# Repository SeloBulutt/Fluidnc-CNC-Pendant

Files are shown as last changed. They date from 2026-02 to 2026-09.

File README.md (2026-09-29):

# 🎛️ CNC Pendant for FluidNC

**Arduino Nano ESP32 tabanlı (farklı mikroişlemci kullanabilirsiniz), ST7789 TFT ekranlı, FluidNC uyumlu CNC kumanda paneli.**

> Tasarım & Geliştirme: **VOLTveTORK**  
> Sürüm: **v7.0** — Modüler Mimari, SD Kart G-Code Çalıştırma & Canlı İlerleme Takibi, NVS Durdurma Noktası Kayıt Sistemi, Z Probe Desteği, PWM Ekran Parlaklığı, Asenkron WiFi Tarama, Gelişmiş Güvenlik & Performans İyileştirmeleri

---

## 📸 Özellikler

### Temel Özellikler
- ✅ FluidNC ile **UART + WiFi/TCP** çift kanallı haberleşme
- ✅ Gerçek zamanlı **Machine Position (MPos)** ve **Work Position (WPos)** gösterimi
- ✅ Rotary encoder ile hassas jog kontrolü (interrupt tabanlı, 60ms throttle)
- ✅ 4 buton: HOME / ZERO / EKSEN / HIZ-STEP
- ✅ Encoder kısa tıklama + uzun basma (500ms) desteği
- ✅ X, Y, Z eksen seçimi
- ✅ Durum göstergesi: IDLE / RUN / HOLD / ALARM / HOME / JOG / DOOR
- ✅ Homed durumu takibi
- ✅ **Z Probe Desteği** (G38.2 ile derinlik ve hız ayarlı otomatik prob)
- ✅ **PWM Ekran Parlaklık Kontrolü** (4 kademeli arka ışık seviyesi)
- ✅ **Ayar Kalıcılığı (Preferences / NVS)** (Step, Hız, Eksen ve Parlaklık hafızada saklanır)
- ✅ **Tam Modüler C++ Mimarisi** (Bakımı ve geliştirmesi kolay 5 bağımsız modül)
- ✅ **Non-blocking Altyapı** (delay() içermeyen pop-up ve arka planda asenkron WiFi işlemleri)
- ✅ **Gelişmiş Güvenlik:** RUN, HOLD ve ALARM durumlarında kazara hareketi önleyen jog kilidi
- ✅ Popup bildirimleri (non-blocking)
- ✅ **Alt menülerde sınırsız bekleme süresi** (Otomatik çıkış kaldırıldı)
- ✅ **SD Kart Dosya Gezgini** (`$SD/List` & `$SD/Run` ile doğrudan pendant üzerinden G-code dosya listeleme ve çalıştırma)
- ✅ **G-Code Ön İzleme Ekranı** (SD karttaki dosyanın G-code satırlarını kaydırmalı olarak görüntüleme ve AXIS butonuyla başlatma)
- ✅ **Canlı İş İlerleme Ekranı (SCR_JOB_PROGRESS)** (İlerleme çubuğu, yüzde, senkron aktif G-code satırı, Feed ve Spindle bilgileri ile anlık takip)
- ✅ **Durdurma Noktası Kayıt Sistemi (NVS Flash)** (Duraklatma veya Alarm anında kalınan satır no, G-code komutu, WPos koordinatları ve dosya adı kalıcı belleğe kaydedilir)
- ✅ **SPEED Butonu ile Duraklat / Devam Et** (Kesim anında Feed Hold `!` ile duraklatma ve Cycle Start `~` ile devam)
- ✅ **Kesim Anı Tuş Güvenliği** (Kesim sırasında yanlışlıkla basılmaları önlemek için ZERO tuşu ve Jog kilitlenir)

### 🆕 v7.0 — Modüler Mimari, Non-blocking Yapı, Z Probe ve Performans İyileştirmeleri

#### 🔧 Çözülen Sorunlar & Yapılan İyileştirmeler

| Sorun / İhtiyaç | Açıklama | Çözüm |
|---|---|---|
| **Pop-up Delay Bloklaması** | Pop-up bildirimleri gösterilirken `delay()` kullanıldığı için sistem geçici olarak kilitleniyor, veri akışı duruyordu. | **Non-blocking Pop-up** mimarisine geçildi (`PopupState`). Bildirimler arka planda sayılır, sistem akışı kesilmez. |
| **WiFi Bağlantı Bloklaması** | `while(WiFi.status())` döngüsü WiFi bağlanırken tüm sistemi bloke ediyor ve ekranı donduruyordu. | **State Machine (Durum Makinesi)** altyapısına geçildi (`wcsState`). Bağlantı arka planda kurulur. |
| **WiFi Tarama Donması** | Ağ taraması yapılırken (`scanNetworks`) tüm ekran ve arayüz donuyordu. | **Asenkron WiFi taraması** (`WiFi.scanNetworks(true)` + polling) eklendi; tarama arka planda yapılır. |
| **Heap Parçalanması (Çökme Riski)** | Dinamik `String +=` birleştirmeleri ESP32 RAM belleğinde parçalanmaya (fragmentation) yol açıyordu. | Sabit boyutlu **char buffer (`char fcBuf[128]`)** yapısına geçildi, bellek sızıntısı ve çökme riski ortadan kaldırıldı. |
| **Ekran Titremesi (Flicker)** | Her ekran yenilemede `fillScreen()` çağrılması gözü yoran titremelere neden oluyordu. | **Partial Update (Kısmi Güncelleme)** ile sadece değişen alanlar çizilerek titreme minimuma indirildi. |
| **Pil Dalgalanması** | Her döngüde analog voltaj okunması pil yüzdesinde sürekli oynamalara neden oluyordu. | **Önbellekleme & Filtre:** Pil 10 saniyede bir, 8 örnek ortalaması alınarak gürültüden arındırıldı. |
| **RUN/HOLD Modunda İstem Dışı Jog** | Makine çalışırken encoder'a yanlışlıkla dokunulması iş parçasına çarpma riski doğuruyordu. | `ST_RUN`, `ST_HOLD` ve `ST_ALARM` durumlarında encoder jog komutları **yazılımsal olarak engellendi**. |
| **Yeniden Başlatmada Ayar Kaybı** | Cihaz kapatıldığında step, hız, eksen ve ekran ayarları varsayılana dönüyordu. | **Preferences (NVS)** API'si ile ayarlar kalıcı hafızaya kaydedildi; açılışta otomatik geri yüklenir. |
| **Monolitik Kod Karmaşası** | 2400+ satırlık tek `.ino` dosyası kodun bakımını, takibini ve geliştirilmesini zorlaştırıyordu. | Kod **5 modüle ayrıldı** (`config`, `input`, `fluidnc`, `wifi_mgr`, `display`). |
| **SD Kart Dosya Başlatma** | SD karttaki G-code dosyaları pendant üzerinden görüntülenemiyor ve başlatılamıyordu. | FluidNC `$SD/List` ve `$SD/Run` entegrasyonu sağlandı; menüye **SD Kart Dosya Gezgini** ve **Ön İzleme** eklendi. |
| **G-Code İlerleme & Satır Takibi** | Kesim sırasında makinenin hangi satırda olduğu ve dosya ilerlemesi kumanda ekranında izlenemiyordu. | **Canlı İş İlerleme Ekranı** (`SCR_JOB_PROGRESS`) geliştirildi; `Ln:` veya `sdPercent` ile senkron aktif G-code satır gösterimi sağlandı. |
| **Durdurma Anında Bilgi Kaybı** | Acil durdurma, duraklatma veya alarmlarda işin nerede kaldığı bilinemiyordu. | **NVS Kalıcı Durdurma Noktası Kaydı** eklendi; dosya adı, satır numarası, o satırdaki G-code komutu ve koordinatlar Flash hafızaya kaydedilir. |
| **E-Stop / Alarm Anında Çökme** | Acil stop butonuna basıldığında pendant çöküyor ve bootloop döngüsüne giriyordu. | Format hatası (`%%.1f`) ve `prefs.begin()` güvenlik kontrolleri düzeltildi, çökme riski tamamen ortadan kaldırıldı. |
| **Kesim Anında Yanlışlıkla Sıfırlama** | Kesim sırasında ZERO tuşuna basılması parça sıfırını bozabilirdi. | `ST_RUN` ve `ST_HOLD` durumlarında ZERO butonu yazılımsal olarak devre dışı bırakıldı. |

#### ✨ Yeni Eklenen Özellikler

- ✅ **Z Probe Ekranı (#18)** — Menüye yeni "Z Probe" özelliği eklendi! `G38.2` komutu ile hassas sıfırlama yapılır. Menü üzerinden prob derinliği (`-1` ile `-50 mm`) ve prob hızı (`20` ile `500 mm/dk`) encoder ile ayarlanabilir. IDLE modunda Eksen butonuna basılarak tetiklenir.
- ✅ **PWM Ekran Parlaklık Ayarı (#19)** — A2 (TFT_BLK) pini üzerinden 4 kademeli PWM parlaklık kontrolü (%25, %50, %75, %100). WiFi menüsünden doğrudan değiştirilebilir.
- ✅ **Kalıcı Ayar Hafızası (NVS / Preferences) (#20)** — Step boyutu, Jog hızı, seçili eksen ve ekran parlaklık seviyesi cihaz kapatılsa bile hafızada saklanır.
- ✅ **RUN/HOLD Jog Kilidi (#1)** — İşleme veya alarm durumlarında istenmeyen fiziksel jog hareketlerini engelleyen güvenlik koruması.
- ✅ **Float Epsilon Karşılaştırma (#8)** — Pozisyon değişimlerinde hassas floating point karşılaştırması (`fabsf(a-b) > 0.0005`).
- ✅ **Merkezi MachineState Enum (#13)** — String karşılaştırmaları yerine enum mimarisi ile maksimum hız ve güvenilirlik.
- ✅ **SD Kart Dosya Gezgini (`$SD/List` & `$SD/Run`)** — UART veya WiFi üzerinden SD karttaki `.nc`, `.gcode` dosyaları listelenir, encoder ile seçilir.
- ✅ **G-Code Ön İzleme Ekranı (`SCR_SD_PREVIEW`)** — SD karttaki dosyaya tıklandığında hemen başlatılmaz; G-code satırları kaydırmalı olarak incelenir, EKSEN (AXIS) butonu ile başlatılır.
- ✅ **Canlı İş İlerleme ve Takip Ekranı (`SCR_JOB_PROGRESS`)** — İş başlatıldığında otomatik açılır:
  - Duruma göre renkli başlık (İŞ ÇALIŞIYOR / DURAKLATILDI / ALARM DURUMU!)
  - Dinamik ilerleme çubuğu (yüzde ve anlık satır / toplam satır sayısı)
  - Feed hızı, Spindle devri ve dosya adı göstergesi
  - Makine hareketiyle senkron olarak kayan canlı G-code satırları
  - HOME butonu ile ana menüye dönülebilir, menüden tekrar ilerleme ekranına girilebilir
- ✅ **Durdurma Noktası Kayıt Sistemi (NVS Flash)** — Kesim anında SPEED ile duraklatıldığında veya beklenmedik bir E-Stop/Alarm oluştuğunda dosya adı, kalınan satır, o satırdaki G-code komutu, WPos koordinatları kalıcı hafızaya yazılır. Cihaz kapansa bile silinmez.
- ✅ **E-Stop / Alarm Güvenliği ve Çökme Koruması** — Bellek taşması ve `printf` formatlama hataları giderilerek E-Stop anındaki reset/çökme sorunu tamamen çözüldü.
- ✅ **Kesim Anında ZERO Tuşu Güvenlik Kilidi** — Kesim esnasında (`ST_RUN`, `ST_HOLD`) ZERO butonuna basılsa bile koordinat sıfırlama engellendi.

### v6.0 — mDNS Otomatik IP Keşfi, TCP Donma Çözümü, UART Öncelikli İletişim

#### 🔧 Çözülen Sorunlar

| Sorun | Açıklama | Çözüm |
|---|---|---|
| **TCP Bağlantı Donması** | `tcpClient.connect()` FluidNC'ye ulaşamadığında ~5 saniye boyunca sistemi tamamen donduruyordu. Bu her 5 saniyede bir tekrarlanarak "5sn dondur, 5sn çalış" döngüsü oluşturuyordu. | `connect()` çağrısına **1000ms timeout** parametresi eklendi. Sistem artık en fazla 1 saniye bloke olur. |
| **Manuel IP Girişi Zorluğu** | FluidNC'nin IP adresini kullanıcının encoder ile tek tek girmesi gerekiyordu. IP adresi değiştiğinde tekrar elle güncelleme yapılmalıydı. | **mDNS (ESPmDNS)** ile FluidNC'nin ağda yayınladığı `fluidnc.local` adresi otomatik keşfedilir. WiFi bağlantısı kurulduğunda IP otomatik bulunur. |
| **UART Aktifken Gereksiz TCP Denemeleri** | UART bağlantısı aktifken bile TCP reconnect denemeleri yapılıyor, bu her denemede sistemi kısa süreli donduruyordu. | UART aktifken TCP reconnect denemeleri **tamamen engellendi**. Sadece UART pasif olduğunda TCP bağlantısı denenir. |
| **Header'da Belirsiz Bağlantı Göstergesi** | Bağlantı durumu ikonunda UART mı yoksa WiFi mı kullanıldığı net anlaşılmıyordu. | Header'da **`[UART]`** (yeşil) ve **`[WiFi]`** (yeşil/sarı) olarak ayrı ayrı gösterilir. Aktif kanal net şekilde belirtilir. |
| **TCP Reconnect Sıklığı** | Başarısız TCP bağlantı denemelerinde her 5 saniyede bir yeniden deneme yapılıyordu, bu da sürekli donma hissi yaratıyordu. | **Üstel geri çekilme (exponential backoff)** eklendi: İlk 3 deneme → 5sn, sonraki 7 → 15sn, ardından → 30sn aralıklarla deneme yapılır. |

#### ✨ v6.0 ile Eklenen Özellikler

- ✅ **mDNS ile Otomatik IP Keşfi** — WiFi bağlantısı kurulduğunda FluidNC'nin ağdaki IP adresi **otomatik olarak keşfedilir** (`ESPmDNS` kütüphanesi). Manuel IP girişine gerek kalmaz. TCP bağlantısı 3 kez başarısız olursa mDNS ile IP tekrar aranır.
- ✅ **UART Öncelikli İletişim** — UART bağlantısı aktifse (500ms içinde veri geliyorsa) tüm komutlar UART üzerinden gönderilir. UART pasif olduğunda otomatik olarak TCP'ye geçilir. UART aktifken TCP reconnect denemeleri yapılmaz.
- ✅ **Header'da Akıllı Bağlantı Göstergesi** — `[UART]` yeşil (UART aktif) / `[WiFi]` yeşil (TCP bağlı) / `[WiFi]` sarı (WiFi bağlı ama TCP yok) / `[]` kırmızı (bağlantı yok)
- ✅ **Üstel Geri Çekilmeli TCP Reconnect** — Başarısız bağlantı denemelerinde aralık otomatik olarak artar (5s → 15s → 30s). Her 3 başarısız denemede mDNS ile IP tekrar keşfedilir.
- ✅ **WiFi Menüsünde "Oto IP Bul"** — Manuel IP giriş ekranı kaldırıldı, yerine **mDNS tabanlı otomatik IP keşfi** butonu eklendi. Tek tıklama ile FluidNC'nin IP'si ağda aranır ve bulunursa kaydedilir.

### v5.0 — WiFi, Soft Reset, Duraklama ve Override Kontrolü

- ✅ **Realtime Override Kontrolü** — Program çalışırken (RUN/HOLD durumunda) encoder çevrildiğinde anında FluidNC'ye (±%10) komut gönderimi. Encoder'a tıklama ile override değerini %100'e (reset) döndürme.
- ✅ **Override Kısayolu** — RUN/HOLD modunda EKSEN butonuna basarak doğrudan Feed/Spindle override ekranına erişim.
- ✅ **WiFi Bağlantısı** — ESP32 WiFi üzerinden FluidNC'ye TCP bağlantısı (Port 23)
  - Ağ tarama (RSSI sinyal gücü göstergesi ile)
  - Karakter tekerleği ile şifre girişi (maskeli gösterim)
  - ~~FluidNC IP adresi ayarı (oktet oktet düzenleme)~~ → **v6.0'da mDNS otomatik keşif ile değiştirildi**
  - NVS ile ayarların kalıcı hafızaya kaydı
  - Otomatik bağlantı (kayıtlı SSID varsa başlangıçta bağlanır)
- ✅ **UART/TCP Otomatik Geçiş** — UART aktifse UART, değilse TCP kullanılır (500ms timeout)
- ✅ **Footer'da FluidNC IP** adresi gösterimi (mDNS ile otomatik bulunan veya kayıtlı IP)
- ✅ **Duraklama / Devam** — SPEED butonu ile Feed Hold (`!`) ve Cycle Start (`~`)
- ✅ **Otomatik & Manuel Uyku Modu (Deep Sleep)** — 2 dakika işlem yapılmazsa veya HOME tuşuna uzun basıldığında cihaz 10µA tüketen uyku moduna geçer.
- ✅ **Batarya Görüntüleme** — Sağ üst köşede pil yüzdesini (`[🔋 78%]`) gösterir (A1 pini üzerinden voltaj okuma).
- ✅ **Arka Işık (BLK) Kontrolü** — Uyku modunda ekranın arkasındaki LED aydınlatmasını tamamen keser (A2 pini).
- ✅ **Alarm Kurtarma** — Alarm durumunda:
  - HOME butonu → Kilidi Aç (`$X`)
  - ZERO butonu → Soft Reset (`0x18`)
- ✅ **Bağlamsal Footer** — Makine durumuna göre değişen yardım metni
- ✅ **HOME butonu = Geri / Uyku** — Menü ve alt ekranlarda geri dönüş, ana ekranda 1.5 sn basılı tutulursa derin uyku.

### Menü Sistemi
- ✅ **Feed ve Spindle Override** — Program çalışırken menü dinamik olarak değişerek override ayar seçeneklerini gösterir.
- ✅ **Spindle Kontrolü** — 270° analog gauge, 500 RPM adımlı hedef hız, M3/M5 gönderimi
- ✅ **Jog Hızı Seçimi** — 1000 / 2000 / 3000 mm/dk
- ✅ **Step Boyutu Seçimi** — 0.100 / 0.500 / 1.000 mm
- ✅ **Soğutma Kontrolü** — KAPALI (M9) / FLOOD (M8) / MIST (M7)
- ✅ **Z Probe** — G38.2 ile derinlik ve hız ayarlı otomatik prob alma (v7.0)
- ✅ **WiFi ve Cihaz Ayarları** — Ağ Tara / Şifre Gir / Oto IP Bul / Bağlan-Kes / Ekran Parlaklığı (4 Kademe PWM)

---

## 🔧 Donanım

| Bileşen | Model |
|---|---|
| Mikrodenetleyici | Arduino Nano ESP32 |
| Ekran | 1.9" ST7789 IPS TFT (320×170) |
| Encoder | EC11 Rotary Encoder (SW dahil) |
| CNC Kontrolcü | FluidNC (ESP32-S3) |

---

## 📌 Pin Bağlantıları

### Rotary Encoder
| Encoder | Nano ESP32 |
|---|---|
| CLK (Out A) | D2 |
| DT (Out B) | D3 |
| SW (Buton) | A0 |
| GND | GND |

### Butonlar (Aktif LOW — dahili pull-up)
| Buton | Nano ESP32 |
|---|---|
| HOME | D4 |
| ZERO | D5 |
| EKSEN | A6 |
| HIZ/STEP | A7 |

### ST7789 TFT Ekran (SPI)
| TFT Pin | Nano ESP32 | Not |
|---|---|---|
| SCL / SCK | D13 | Otomatik (SPI) |
| SDA / MOSI | D11 | Otomatik (SPI) |
| CS | D10 | |
| DC | D6 | |
| RES / RST | D7 | |
| BLK | **A2** | Arka ışık (PWM parlaklık kontrolü & Uyku modu) |
| VCC | 3.3V | |
| GND | GND | |

### Pil Ölçümü (Güç Yönetimi)
| Sensör / Pin | Nano ESP32 | Yön |
|---|---|---|
| TP4056 B+ ucu | **A1** (GPIO2) | 100K+100K Voltaj bölücü üzerinden |

### UART → FluidNC ESP32-S3 (Önemli Kablo Revizyonu)

Pendant ile CNC ESP32-S3 kontrol kartı arasındaki bağlantı kablosunda **5 adet kablo** kullanılmalıdır. Besleme kablosundaki parazitlerin sinyal bütünlüğünü bozmasını engellemek için sinyal ve güç topraklamaları (GND) ayrı kablolar üzerinden taşınmalıdır:

1. **TX** (Sinyal)
2. **RX** (Sinyal)
3. **Sinyal GND** (Sadece TX ve RX sinyalleri için topraklama)
4. **5V** (Güç Beslemesi)
5. **Güç GND** (Sadece 5V hattı için ayrı topraklama)

| Nano ESP32 | ESP32-S3 | Açıklama |
|---|---|---|
| D9 (RX1) | GPIO38 (TX) | Sinyal Hattı (FluidNC → Pendant) |
| D8 (TX1) | GPIO39 (RX) | Sinyal Hattı (Pendant → FluidNC) |
| GND | GND | Sinyal Topraklaması (TX ve RX için) |
| VIN / 5V | 5V | Güç Beslemesi |
| GND | GND | Güç Topraklaması (Ayrı hat üzerinden) |

> ⚠️ **DİKKAT:** TX → RX çapraz bağlanır! Sinyal GND ve Güç GND hatları cihaz pinlerinde GND olarak birleşebilir ancak bağlantı kablosu boyunca birbirine değmeyen iki ayrı tel olmalıdır.

---

## 🔋 Güç Yönetimi ve Batarya (Opsiyonel)

Kablo bağımlılığından kurtulmak için Pendant'a bir Li-ion pil entegre edebilirsiniz. En kararlı ve ekran parlaklığını etkilemeyen 5V yükseltici (MT3608) dizilimi aşağıdaki gibidir:

```text
  [Li-ion Pil]
       │
      (B+/B-)
       ▼
  ┌────────────┐ (OUT+)  ┌──────────────┐ (OUT+ 5V)  ┌───────────────┐
  │ TP4056     ├────────►│ MT3608 Boost ├───────────►│ Arduino Nano  │ (VIN'e Girin)
  │ Şarj + Koru│ (OUT-)  │ Voltaj Yüks. │ (OUT- GND) │ ESP32 (VIN/GND)│
  └────────────┘         └──────────────┘            └───────────────┘
```
1. **TP4056:** Uart kablosu takılıyken pili şarj eder. Sistem 2.5V altına düştüğünde çıkışı kesip pili korur (DW01A'lı versiyon).
2. **MT3608 Regülatör:** Pil voltajı ne kadar düşerse düşsün, her zaman anlık olarak 5.0V çıkışa (trimpot ile ayarlayın) yükseltir. Nano ESP32 bu temiz 5V'u kendi kaliteli 3.3V regülatöründen geçirip ekranı sorunsuz besler.

> **Uyku Modu Farkı:** Cihaz hiçbir haberleşme almazsa veya **HOME tuşuna 1.5 sn basılı tutulursa** her şey (ekran ışığı dahil) kapatılır. Bu modda pil ömrü aylarca dayanabilir.

---

## ⚙️ FluidNC Yapılandırması

`config.yaml` dosyasına aşağıdaki bölümleri ekleyin:

```yaml
uart1:
  txd_pin: gpio.38
  rxd_pin: gpio.39
  baud: 115200
  mode: 8N1

uart_channel1:
  uart_num: 1
  report_interval_ms: 75
  message_level: Error
```

> `uart_channel1` sayesinde FluidNC pozisyon bilgisini **otomatik olarak** her 75ms'de gönderir — `?` sorgusu gerekmez.

---

## 💻 Yazılım Kurulumu

### Gerekli Kütüphaneler (Arduino Library Manager)

```
Adafruit ST7789
Adafruit GFX Library
```

> `WiFi.h`, `Preferences.h`, `ESPmDNS.h`, `esp_sleep.h` ve `SPI.h` kütüphaneleri ESP32 çekirdeği ile birlikte gelir.

### Yükleme

1. Arduino IDE'yi açın
2. **Board**: `Arduino Nano ESP32` seçin
3. `CNC_pendant_v7_0_wifi.ino` dosyasını açın (Aynı klasördeki tüm `.h` ve `.cpp` modülleri Arduino IDE tarafından otomatik olarak sekmeler halinde açılacaktır)
4. Gerekli kütüphanelerin kurulu olduğundan emin olun
5. **Upload** butonuna basarak karta yükleyin

---

## 📡 Haberleşme Mimarisi

```
                   ┌─────────────────────┐
                   │   CNC Pendant       │
                   │  (Nano ESP32)       │
                   └──┬──────────┬───────┘
                      │          │
              UART    │          │  WiFi/TCP
           (115200)   │          │  (Port 23)
           ÖNCELİKLİ │          │  YEDEK
                      │          │
                   ┌──┴──────────┴───────┐
                   │     FluidNC         │
                   │    (ESP32-S3)       │
                   └─────────────────────┘
```

### İletişim Öncelik Sırası
1. **UART öncelikli:** UART'tan 500ms içinde veri geliyorsa komutlar **her zaman** UART üzerinden gönderilir
2. **Otomatik TCP geçişi:** UART pasifse ve WiFi/TCP bağlıysa komutlar TCP üzerinden gönderilir
3. **UART aktifken TCP reconnect engeli:** UART bağlantısı varken TCP yeniden bağlanma denemeleri yapılmaz (gereksiz donma engellenir)
4. Pendant her 250ms'de `?` sorgusu göndererek durum bilgisi alır (hem UART hem TCP)
5. TCP bağlantısı kesilirse **üstel geri çekilme** ile yeniden bağlanma denenir (5s → 15s → 30s)

### mDNS Otomatik IP Keşfi Akışı
```
WiFi Bağlantısı Kuruldu
        │
        ▼
  mDNS Başlat ("cncpendant")
        │
        ▼
  "http.tcp" Servisi Ara
        │
   ┌────┴────┐
   │ Bulundu │──► IP Kaydet ──► TCP Bağlan
   └─────────┘
   │ Bulunamadı│──► Kayıtlı IP ile Devam Et
   └──────────┘
        │
  (TCP 3x Başarısız)
        │
        ▼
  mDNS ile Tekrar Ara
```

---

## 🖥️ Ekran Düzeni

### Ana Ekran
```
┌─────────────────────────────────────────────────────┐
│ [IDLE]   CNC PENDANT  [HOMED]  [78%]  [UART]    X  │
├──────────────────┬──────────────────────────────────┤
│   MACHINE POS    │         WORK POS                 │
├──────────────────┼──────────────────────────────────┤
│ X  +125.000      │  +25.000                         │
│ Y   -45.500      │   -5.500   ← aktif eksen (sarı)  │
│ Z    +0.000      │   +0.000                         │
├──────────────────┴──────────────────────────────────┤
│ F:500  S:0  STEP:0.100  192.168.1.105               │
│ [HOME] [ZERO] [AXIS] [SPEED]  Tikla:Menu            │
└─────────────────────────────────────────────────────┘
```

### Bağlantı Durumu Göstergesi (Header)
| İkon | Renk | Anlamı |
|---|---|---|
| `[UART]` | 🟢 Yeşil | UART bağlantısı aktif (öncelikli kanal) |
| `[WiFi]` | 🟢 Yeşil | WiFi bağlı + TCP bağlı |
| `[WiFi]` | 🟡 Sarı | WiFi bağlı, TCP bağlantısı yok |
| `[]` | 🔴 Kırmızı | Bağlantı yok |

### Bağlamsal Footer Metinleri
| Durum | Footer |
|---|---|
| IDLE / HOME | `[HOME] [ZERO] [AXIS] [SPEED]  Tikla:Menu` |
| RUN / JOG | `[SPEED] Duraklat` |
| HOLD | `[SPEED] Devam Et` |
| ALARM | `[ZERO] Reset  [HOME] Kilit Ac` |

---

## 🗂️ Detaylı Menü Sistemi ve Ayarlar

Kumandanın ana ekranındayken **Encoder'a bir kez tıklayarak** ana menüye girebilirsiniz. Menüde gezinmek için encoder çevrilir, seçim yapmak için tıklanır. Menülerden geri dönmek için **HOME** butonuna basabilir veya **Encoder'a uzun basabilirsiniz**. Alt menülerde ve ayarlarda **süre sınırı yoktur**, siz manuel olarak çıkmadıkça ekran ana menüye atmaz.

Makinenin çalışma durumuna (Boşta veya Çalışıyor) göre menü sistemi **dinamik olarak değişir**.

**CNC Menü (IDLE - Boşta)**
```text
┌─────────────────────────────────────────────────────┐
│                      CNC MENU                       │
├─────────────────────────────────────────────────────┤
│   > Spindle Kontrolu                                │
│     Jog Hizi                                        │
│     Step Boyutu                                     │
│     Sogutma                                         │
│     Z Probe                                         │
│     WiFi Ayarlari                                   │
├─────────────────────────────────────────────────────┤
│              Encoder: Sec  |  Tikla: Gir            │
└─────────────────────────────────────────────────────┘
```

**CNC Menü (RUN/HOLD - Çalışırken)**
```text
┌─────────────────────────────────────────────────────┐
│                      CNC MENU                       │
├─────────────────────────────────────────────────────┤
│   > Spindle Override                                │
│     Feed Override                                   │
│     Jog Hizi                                        │
│     Step Boyutu                                     │
│     Sogutma                                         │
├─────────────────────────────────────────────────────┤
│              Encoder: Sec  |  Tikla: Gir            │
└─────────────────────────────────────────────────────┘
```

### 1. Spindle Kontrolü (Makine IDLE / Boşta iken)
Makine boşta iken menüde ilk sırada yer alır. Manuel Spindle kontrolü için kullanılır.

```text
┌─────────────────────────────────────────────────────┐
│ SPINDLE KONTROLU                       [M5 KAPALI]  │
├─────────────────────────────────────────────────────┤
│           . . . .                                   │
│        .    10K    .           HEDEF HIZ:           │
│      .               .                              │
│    5K                 15K         12000             │
│   0                     20K        RPM              │
│            12000                                    │
│             RPM                KAPALI               │
├─────────────────────────────────────────────────────┤
│            Cevir: Hiz Ayarla  |  Tikla: M3 Gonder   │
└─────────────────────────────────────────────────────┘
```

- **Ekran Görünümü:** Yukarıdaki gibi 270° derece dolan analog bir devir saati (gauge) ve sağ panelde Hedef Hız kutucuğu bulunur. 
- **Kullanım:** Encoder çevrildiğinde Hedef Hız 500 RPM'lik adımlarla artar veya azalır. İstenilen hıza gelindiğinde encoder'a tıklandığında `M3` komutuyla Spindle çalıştırılır. Spindle zaten çalışıyorsa, tıklamak `M5` komutuyla Spindle'ı durdurur.

### 2. Override Menüleri (Makine RUN / HOLD iken)
Makine bir G-Code programı işlerken ana menüdeki "Spindle Kontrolü" gizlenir; yerine anlık müdahale için Override (geçersiz kılma) menüleri açılır. 

```text
┌─────────────────────────────────────────────────────┐
│ SPINDLE OVERRIDE                        [M3 AKTIF]  │
├─────────────────────────────────────────────────────┤
│           . . . .                                   │
│        .           .                                │
│      .               .                              │
│     .                 .                             │
│    50%               200%                           │
│             120%                                    │
│           SPINDLE                                   │
├─────────────────────────────────────────────────────┤
│        Cevir: +-10% Aninda  |  Tikla: %100 Reset    │
└─────────────────────────────────────────────────────┘
```

> 💡 **Kısayol:** Program çalışırken ana ekranda **EKSEN (Axis) butonuna basarak** bu menüye doğrudan kısayoldan erişebilirsiniz. Aşağıdaki seçim ekranı açılır:

```text
┌─────────────────────────────────────────────────────┐
│                 OVERRIDE SECIMI                     │
├─────────────────────────────────────────────────────┤
│                                                     │
│                > Feed Override                      │
│                  Spindle Override                   │
│                                                     │
├─────────────────────────────────────────────────────┤
│             Encoder: Sec  |  Tikla: Onayla          │
└─────────────────────────────────────────────────────┘
```
- **Feed Override (İlerleme Hızı):** Çalışan makinenin eksenlerdeki ilerleme hızını anlık olarak %10'luk adımlarla (±%10) değiştirmenizi sağlar. %0 ile %200 arasında renkli (Kırmızı/Sarı/Yeşil) bir gösterge barı üzerinden anlık yüzdenizi görebilirsiniz. Encoder çevrildiğinde **anında FluidNC'ye komut gönderilir**. Encoder'a tıklamak değeri **%100'e sıfırlar (resetler)**.
- **Spindle Override (Devir Hızı):** Aynı şekilde, spindle motorunun devrini iş parçasının durumuna göre anlık (±%10 adımlarla) artırıp azaltmanızı sağlar. Encoder çevrildiğinde **anında FluidNC'ye komut gönderilir**. Encoder'a tıklamak değeri **%100'e sıfırlar (resetler)**.

### 3. Jog Hızı (Jog Speed)
Seçili eksende manuel olarak hareket ettirilirken makinenin ulaşacağı maksimum hızı belirler.
- **Seçenekler:** 1000, 2000, 3000 mm/dk.
- **Kullanım:** Ekranda liste şeklinde görünür. Encoder çevrilerek istenilen hızın üzerine gelinir (yanında `>` işareti belirir) ve tıklanarak aktif edilir. Seçilen hız hafızaya (NVS) kaydedilir.

### 4. Step Boyutu (Step Size)
Encoder'ın her bir tık (çıt) dönüşünde makinenin eksende ne kadar ilerleyeceğini belirler.
- **Seçenekler:** 0.100 mm, 0.500 mm, 1.000 mm.
- **Kullanım:** Hassas yaklaşım veya hızlı hareket için uygun değer encoder ile seçilir. Seçilen değer ana ekranın alt kısmında (Footer) gösterilir ve kalıcı hafızaya kaydedilir.

### 5. Soğutma (Coolant)
Soğutma veya hava sistemlerini manuel olarak devreye almak için kullanılır.
- **Seçenekler:**
  - **M9:** Soğutma Kapalı
  - **M8:** Flood (Su/Sıvı Soğutma)
  - **M7:** Mist (Hava/Sis Soğutma)

### 6. Z Probe (Makine IDLE / Boşta iken)
Takım boyu veya iş parçası sıfırlama işlemlerini pendant üzerinden doğrudan başlatmak için eklenen prob menüsüdür.

```text
┌─────────────────────────────────────────────────────┐
│ Z PROBE                                             │
├─────────────────────────────────────────────────────┤
│ Mevcut Z: +15.250 mm                                │
│                                                     │
│   > DERINLIK:  -10 mm                               │
│     HIZ:       50 mm/dk                             │
│                                                     │
├─────────────────────────────────────────────────────┤
│   AXIS: Baslat (G38.2)  |  Tikla: Secim Degistir    │
└─────────────────────────────────────────────────────┘
```

- **Mevcut Z:** Çalışma koordinat sistemindeki (WCS) anlık Z yüksekliğini canlı olarak gösterir.
- **Derinlik (Depth):** Probun maksimum ineceği mesafe (`-1 mm` ile `-50 mm` arasında 1'er mm adımlarla ayarlanabilir).
- **Hız (Feed):** Probun arama hızı (`20 mm/dk` ile `500 mm/dk` arasında 10'ar mm/dk adımlarla ayarlanabilir).
- **Kullanım:**
  - **Encoder Çevirme:** Seçili olan parametrenin (Derinlik veya Hız) değerini artırır / azaltır.
  - **Encoder Tıklama:** Düzenlenecek parametreyi değiştirir (Derinlik ↔ Hız arasında geçiş yapar).
  - **EKSEN (AXIS) Butonu:** Probu başlatır (`G38.2 Z{derinlik} F{hiz}`). Güvenlik gereği prob işlemi **sadece makine IDLE (Boşta)** iken çalıştırılabilir.
  - **HOME Butonu / Encoder Uzun Basma:** Menüye geri döner.

### 7. SD Kart Dosya Gezgini ve G-Code Ön İzleme
Kumanda ana menüsünden **SD Kart** seçeneğine tıklandığında FluidNC'ye `$SD/List` komutu gönderilir ve karttaki G-code dosyaları ekranda listelenir:

```text
┌─────────────────────────────────────────────────────┐
│ SD KART DOSYALARI                                   │
├─────────────────────────────────────────────────────┤
│   > PARCA_1.NC                                      │
│     ROUTER_TEST.GCODE                               │
│     DENEME.NC                                       │
│     TABLA_DUZLEME.NC                                │
├─────────────────────────────────────────────────────┤
│    Encoder: Sec  |  Tikla: On Izle  |  HOME: Geri   │
└─────────────────────────────────────────────────────┘
```

- **G-Code Ön İzleme:** Listeden bir dosyaya tıklandığında dosya doğrudan çalıştırılmaz; önce **Ön İzleme Ekranı** açılır. Bu ekranda dosyanın içindeki G-code satırları listelenir:
  - **Encoder Çevirme:** Satırlar arasında yukarı / aşağı kaydırma yapar.
  - **EKSEN (AXIS) Butonu:** Dosyayı çalıştırmayı başlatır (`$SD/Run=/dosya_adi.nc`).
  - **HOME Butonu:** Listeye geri döner.

```text
┌─────────────────────────────────────────────────────┐
│ ON IZLEME: PARCA_1.NC                               │
├─────────────────────────────────────────────────────┤
│   1: G21 G90 G17                                    │
│   2: G0 Z15.000                                     │
│   3: M3 S12000                                      │
│ > 4: G0 X0.000 Y0.000                               │
│   5: G1 Z-1.500 F300                                │
├─────────────────────────────────────────────────────┤
│     AXIS: Baslat  |  Cevir: Kaydir  |  HOME: Geri   │
└─────────────────────────────────────────────────────┘
```

### 8. Canlı İş İlerleme Ekranı (SCR_JOB_PROGRESS)
SD karttan veya harici bir göndericiden (PC, WebUI vb.) bir iş başlatıldığında kumanda otomatik olarak **İş İlerleme Ekranı**na geçer:

```text
┌─────────────────────────────────────────────────────┐
│ IS CALISIYOR                              [RUN] 64% │
├─────────────────────────────────────────────────────┤
│ Dosya: PARCA_1.NC                                   │
│ Satir: 1420 / 2218                  [=========>   ] │
│ Feed:  1200 mm/dk        Spindle: 14000 RPM         │
├─────────────────────────────────────────────────────┤
│   1418: G1 X45.200 Y12.400                          │
│   1419: G1 X46.800 Y12.900                          │
│ > 1420: G1 X48.500 Y13.500 F1200                    │
│   1421: G1 X50.000 Y14.100                          │
├─────────────────────────────────────────────────────┤
│  SPEED: Duraklat | HOME: Ana Menu | AXIS: Override  │
└─────────────────────────────────────────────────────┘
```

- **Canlı Satır Senkronizasyonu:** Makine işledikçe ekrandaki aktif satır vurgulanarak ilerler. FluidNC'den `Ln:` bilgisi gelmediği durumlarda SD ilerleme yüzdesi üzerinden akıllı hesaplama yapılarak satır kaydırma makineyle tam senkron çalışır.
- **SPEED Butonu:** Kesim anında basıldığında programı duraklatır (`!`) ve kalınan yeri NVS hafızaya kaydeder. Tekrar basıldığında (`~`) devam ettirir.
- **HOME Butonu:** İlerleme ekranından ana menüye dönmenizi sağlar; iş arka planda çalışmaya devam eder ve menüden tekrar ilerleme sayfasına dönülebilir.

### 9. NVS Durdurma Noktası Kayıt Sistemi (Kaldığı Yer Bildirimi)
İşleme sırasında SPEED ile duraklatıldığında veya beklenmedik bir acil durum/alarm (E-Stop, limit switch tetiklenmesi vb.) meydana geldiğinde, pendant o anki durumu ESP32'nin **kalıcı Flash belleğine (NVS)** kaydeder:
- Dosya adı
- Kalınan G-code satır numarası
- O satırdaki G-code komut metni
- WPos (İş Koordinatları: X, Y, Z)
- İlerleme yüzdesi (%)

Pendant yeniden başlatılsa dahi bu bilgiler silinmez. Ekranda kalınan noktayı gösteren bilgi kartı açılır; böylece kullanıcı işi hangi koordinat ve satırdan devam ettireceğini güvenle bilir.

### 10. WiFi Ayarları ve Cihaz Yönetimi
FluidNC kontrol kartına kablosuz olarak (TCP Port 23 üzerinden) bağlanmak ve ekran parlaklığını yönetmek için kullanılan menüdür. Girilen tüm değerler ve ayarlar ESP32'nin **kalıcı hafızasına (NVS)** kaydedilir. Cihaz her açıldığında bu bilgilere göre otomatik bağlanmayı dener ve kaydedilen parlaklık seviyesini uygular.

```text
┌─────────────────────────────────────────────────────┐
│ WIFI AYARLARI                              [ON/OFF] │
├─────────────────────────────────────────────────────┤
│   > Ag Tara                                         │
│     Sifre Gir                                       │
│     Oto IP Bul                                      │
│     Baglan / Kes                                    │
│     Parlaklik                                       │
│     Geri Don                                        │
├─────────────────────────────────────────────────────┤
│ AG: MyNetwork                                       │
└─────────────────────────────────────────────────────┘
```

- **Ağ Tara (Scan):** Tıklandığında ortamdaki WiFi ağları **asenkron olarak (ekran donmadan)** taranır. Ağlar, sinyal güçlerine (RSSI / dBm) göre listelenir. Encoder ile bağlanmak istediğiniz ağın üzerine gelip tıklayarak SSID'yi seçmiş olursunuz.
- **Şifre Gir:** Ekrandaki karakter tekerleği (harfler, sayılar ve özel karakterler) üzerinden şifre girilir. Encoder çevrilerek karakter seçilir, tıklanarak eklenir. Şifre ekranda gizlenmiş maskeli yapıda gösterilir. 
  - **Silme (Backspace):** Hatalı girişte **Encoder'a uzun basılarak** son karakter silinir.
  - **Kaydetme:** Şifre girişini bitirdiğinizde **EKSEN butonuna** basarak şifreyi kaydedersiniz.
- **Oto IP Bul (mDNS):** WiFi bağlantısı kurulu iken bu seçeneğe tıklandığında **mDNS** ile ağdaki FluidNC cihazının IP adresi otomatik aranır. Bulunursa IP kaydedilir ve TCP bağlantısı başlatılır. WiFi bağlı değilse uyarı verir.
- **Bağlan / Kes:** Ayarlar tamamlandığında bu seçeneğe tıklayarak TCP bağlantısını başlatabilirsiniz. Non-blocking state-machine sayesinde bağlantı sırasında sistem donmaz.
- **🆕 Parlaklık (PWM):** Tıklandığında ekran arka aydınlatma şiddeti 4 kademede döngüsel olarak değişir (`1/4 (%25)` → `2/4 (%50)` → `3/4 (%75)` → `4/4 (%100)`). Yapılan seçim anında ekrana yansıtılır ve kalıcı hafızaya kaydedilir.
- **Geri Dön:** Ana menüye döner.

---

## 🕹️ Buton Fonksiyonları ve Kontroller

### Ana Ekran Kontrolleri
| Kontrol | Fonksiyon |
|---|---|
| **Encoder Çevirme** | Seçili eksende jog hareketi yaptırır. <br>*(Güvenlik: RUN/HOLD/ALARM modlarında istenmeyen hareketleri önlemek için kilitlidir)* |
| **Encoder Tıklama** | Ana Menüye giriş yapar |
| **HOME Butonu (Kısa)** | Tüm eksenleri Home'a gönderir (`$H`). Alarm durumunda kilit açar (`$X`). |
| **HOME Butonu (Uzun 1.5s)**| Cihazın ekranını kapatıp **Derin Uykuya (Deep Sleep)** geçirir. |
| **ZERO Butonu** | **IDLE:** O an aktif olan ekseni sıfırlar (`G92`). <br> **ALARM:** Soft Reset atar (`0x18`). <br> **RUN/HOLD:** İşlev devre dışı (kazara sıfırlama/iş bozulmasını önleme kilidi). |
| **EKSEN Butonu** | **IDLE (Boşta):** X → Y → Z eksenleri arasında sırayla geçiş yapar. <br> **RUN/HOLD:** Override Kısayol Menüsünü açar. |
| **HIZ/STEP (SPEED) Butonu** | **IDLE:** Step/Hız ayarını değiştirir (seçimler NVS'ye kaydedilir). <br> **RUN:** Programı Duraklatır (`!`) ve kaldığı noktayı NVS Flash hafızaya kaydeder. <br> **HOLD:** Programı devam ettirir (`~`). |

### Menü İçi Navigasyon
| Kontrol | Fonksiyon |
|---|---|
| **Encoder Çevirme** | Menü öğeleri, şifre harfleri, IP oktetleri veya Probe değerleri arasında gezinme |
| **Encoder Tıklama** | Seçili öğeye gir / onayla / Probe'da parametre değiştir (Derinlik ↔ Hız) |
| **Encoder Uzun Basma** | Bir üst menüye geri dön / Şifre ekranında son karakteri sil |
| **HOME Butonu** | Hangi menüde olursanız olun geri dönmenizi sağlar |
| **EKSEN Butonu** | WiFi şifre ekranında kaydetme; **Z Probe ekranında prob hareketini (G38.2) başlatma** |
| **Sınırsız Bekleme** | Menülerde otomatik çıkış yoktur, çıkmak için HOME veya Encoder'a uzun basana kadar kapanmaz. |

---

## 📡 Durum Göstergeleri

### Makine Durumu
| Durum | Renk | Açıklama |
|---|---|---|
| IDLE | 🟢 Yeşil | Makine boşta |
| RUN | 🔵 Cyan | Program çalışıyor (jog kilitli) |
| HOLD | 🟡 Sarı | Duraklatıldı (jog kilitli) |
| ALARM | 🔴 Kırmızı | Alarm durumu (jog kilitli) |
| HOME | 🟠 Turuncu | Homing işlemi |
| JOG | 🔵 Cyan | Jog hareketi |
| DOOR | 🔴 Kırmızı | Kapı açık |

### Bağlantı Durumu (Header)
| İkon | Renk | Anlamı |
|---|---|---|
| `[UART]` | 🟢 Yeşil | UART aktif — kablolu bağlantı öncelikli |
| `[WiFi]` | 🟢 Yeşil | WiFi + TCP bağlı — kablosuz iletişim aktif |
| `[WiFi]` | 🟡 Sarı | WiFi bağlı, TCP bağlantısı yok |
| `[]` | 🔴 Kırmızı | Bağlantı yok |

---

## 📁 Dosya Yapısı

v7.0 ile birlikte monolitik kod yapısı, bakım ve geliştirme kolaylığı sağlayan 5 bağımsız modüle ayrılmıştır:

```
CNC_pendant_v7.0 wifi/
├── 3D Boyutlu Tasarım Dosyası/
├── CNC_pendant_v7.0 wifi/
│   └── CNC_pendant_v7_0_wifi/
│       ├── CNC_pendant_v7_0_wifi.ino # Ana orchestrator (setup, loop, durum makineleri)
│       ├── config.h                  # Pin, renk, sabitler, enum ve struct tanımları
│       ├── input.h / input.cpp       # Encoder ISR, buton debounce, kısa/uzun basma
│       ├── fluidnc.h / fluidnc.cpp   # UART/TCP komut gönderimi, status parse, realtime
│       ├── wifi_mgr.h / wifi_mgr.cpp # WiFi bağlantı state machine, async scan, mDNS, NVS
│       └── display.h / display.cpp   # ST7789 TFT ekran çizimi, partial update, gauge'ler, SD gezgini & ilerleme ekranı
└── README.md                         # Proje dokümantasyonu
```

---

## 🔌 Bağlantı Şeması

```
Arduino Nano ESP32              FluidNC ESP32-S3
─────────────────────────────────────────────────
D9  (RX1)  ←────(Sinyal)───── GPIO38 (UART1 TX)
D8  (TX1)  ─────(Sinyal)─────→ GPIO39 (UART1 RX)
GND        ───(Sinyal GND)─── GND
VIN / 5V   ─────(Güç 5V)───── 5V
GND        ────(Güç GND)───── GND

        WiFi/TCP (Port 23)
        ←────────────────→     (kablosuz alternatif)

ST7789 TFT          EC11 Encoder        Butonlar
───────────         ────────────        ────────
D13 ← SCK           D2 ← CLK           D4 ← HOME
D11 ← MOSI          D3 ← DT            D5 ← ZERO
D10 ← CS            A0 ← SW            A6 ← EKSEN
D6  ← DC            GND ← GND          A7 ← HIZ
D7  ← RST
A2  ← BLK (PWM)
3V3 ← VCC
GND ← GND
```

---

## 📜 Lisans

Bu proje açık kaynaklıdır. Kişisel ve eğitim amaçlı serbestçe kullanılabilir.

---

## 👤 Geliştirici

**VOLTveTORK**

FluidNC projesi: [github.com/bdring/FluidNC](https://github.com/bdring/FluidNC)

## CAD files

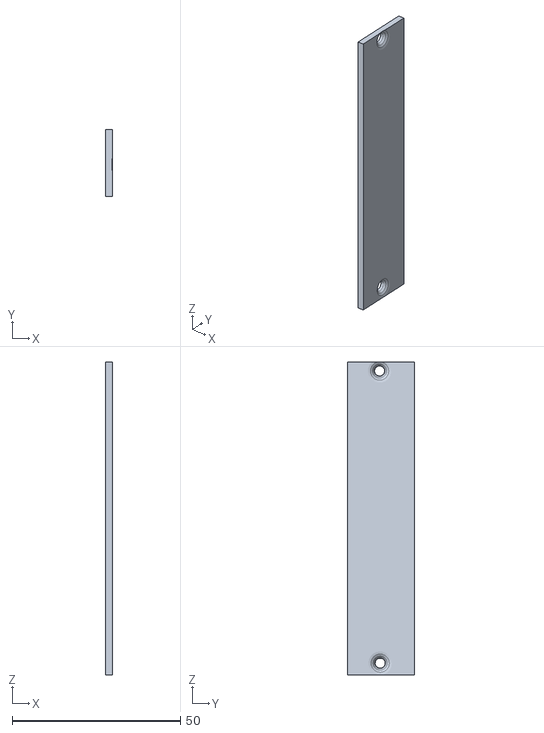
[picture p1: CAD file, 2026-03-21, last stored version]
3D Boyutlu Tasarım Dosyası/pil kapağı.stl
2.00 x 20.0 x 93.0

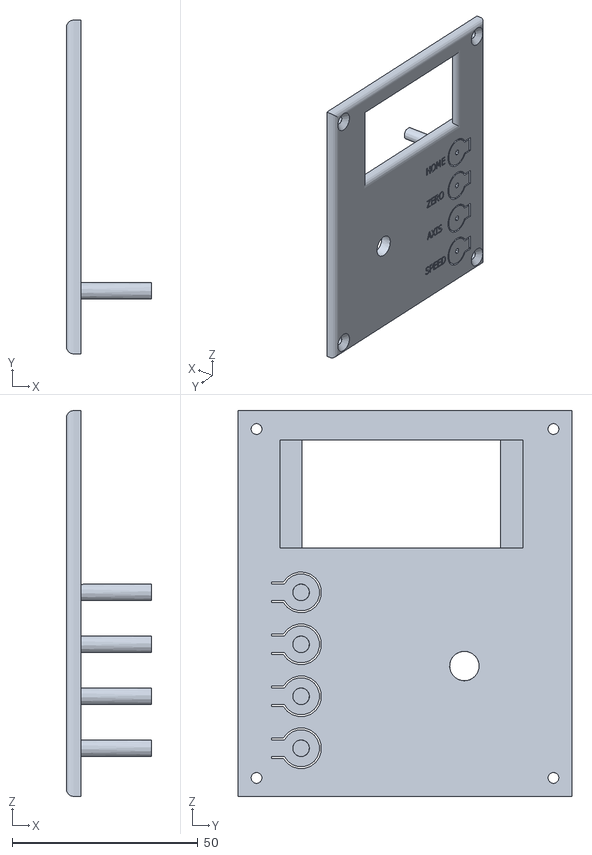
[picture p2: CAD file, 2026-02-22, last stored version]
3D Boyutlu Tasarım Dosyası/kumanda kapağı.stl
23.0 x 90.0 x 104.0

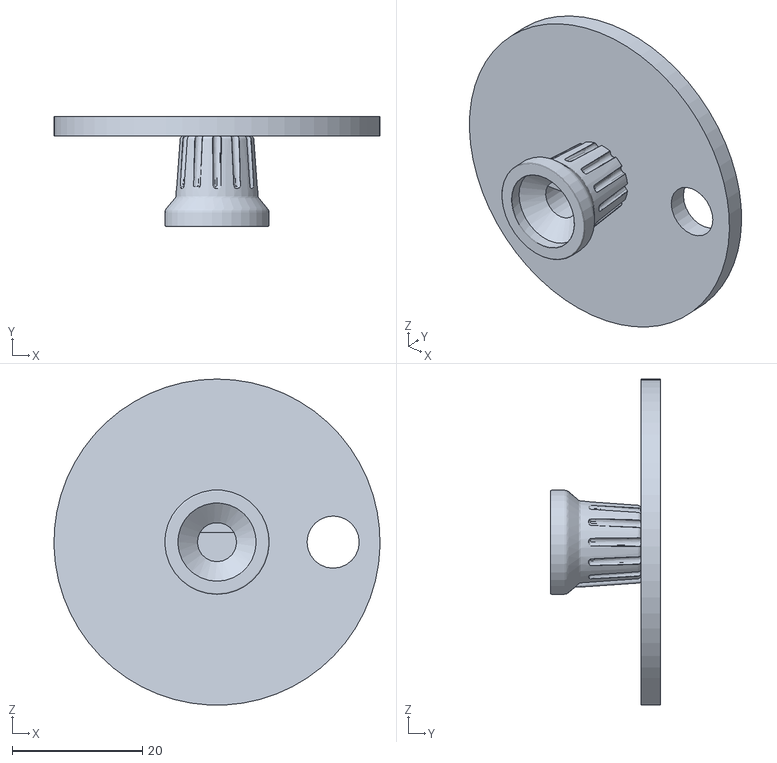
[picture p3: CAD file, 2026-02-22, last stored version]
3D Boyutlu Tasarım Dosyası/rotary knob.stl
50.0 x 16.9 x 50.0

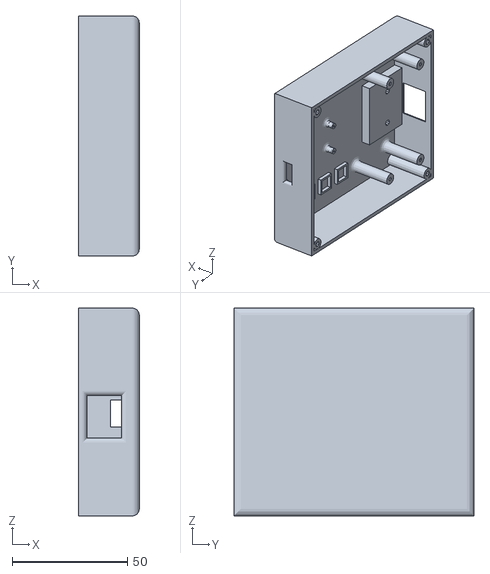
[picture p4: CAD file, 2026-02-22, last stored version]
3D Boyutlu Tasarım Dosyası/kumanda.stl
26.3 x 104.0 x 90.0

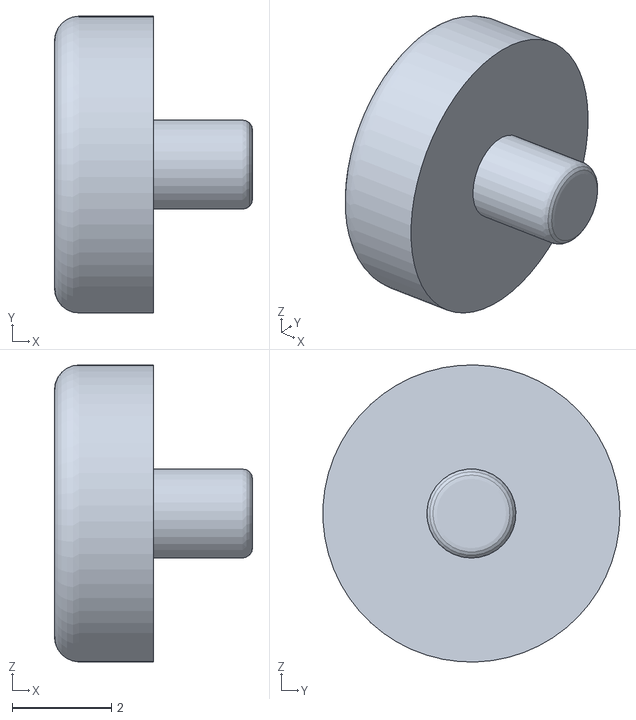
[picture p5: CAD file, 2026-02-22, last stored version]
3D Boyutlu Tasarım Dosyası/TUŞ.stl
4.00 x 6.00 x 6.00

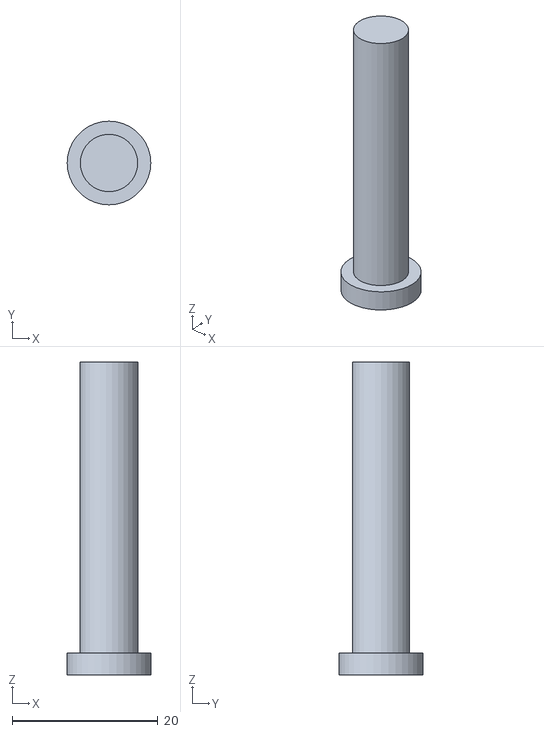
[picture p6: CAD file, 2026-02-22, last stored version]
3D Boyutlu Tasarım Dosyası/KNOOB PARÇASI.stl
11.5 x 11.5 x 43.0

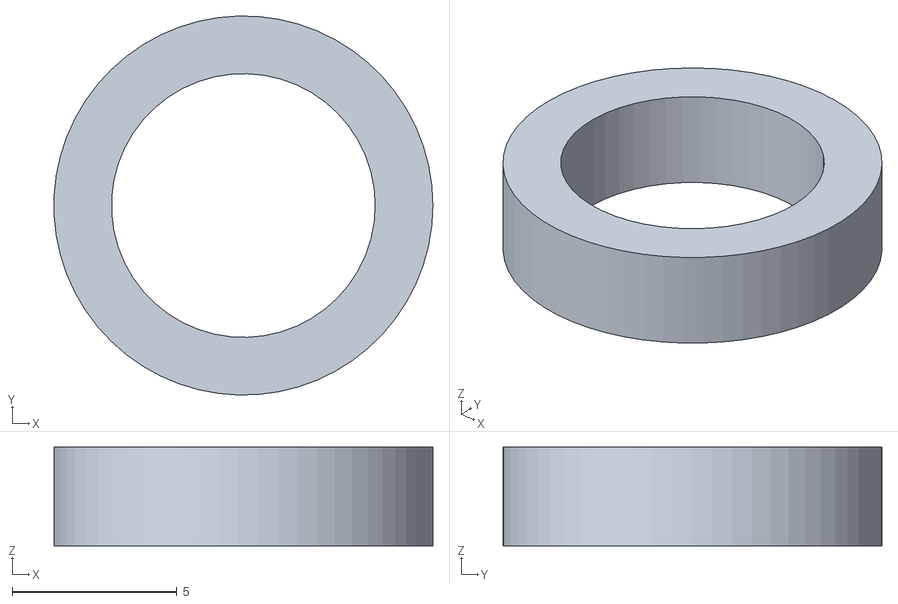
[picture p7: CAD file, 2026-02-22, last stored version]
3D Boyutlu Tasarım Dosyası/KNOB PARÇASI SABİTLEME.stl
11.5 x 11.5 x 3.00

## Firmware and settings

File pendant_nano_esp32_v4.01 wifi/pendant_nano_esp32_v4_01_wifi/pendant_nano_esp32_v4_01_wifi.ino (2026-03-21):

/**
 * =====================================================
 *  CNC Pendant — Arduino Nano ESP32
 *  v4.01 wifi — Wifi bağlantısı — Soft reset ve duraklama eklendi — Uyku modu 
 * =====================================================
 *
 * FluidNC config.yaml:
 *   uart1:
 *     txd_pin: gpio.38
 *     rxd_pin: gpio.39
 *     baud: 115200
 *     mode: 8N1
 *   uart_channel1:
 *     uart_num: 1
 *     report_interval_ms: 75
 *     message_level: Error
 *
 * BAĞLANTI: (aynı v2.8)
 *   Encoder CLK→D2, DT→D3, SW→D12
 *   Butonlar HOME→D4, ZERO→D5, AXIS→A6, SPEED→A7
 *   TFT CS→D10, DC→D6, RST→D7
 *   UART RX1→D9, TX1→D8
 *
 * Alarm Durumunda:
 *   Home: Kilidi Aç
 *   Zero: Soft Reset
 *
 * Hareket Halinde:
 *   Speed: Duraklatma
 *
 *
 *
 * KÜTÜPHANEler: Adafruit ST7789, Adafruit GFX Library
 * =====================================================
 */

#include <Adafruit_GFX.h>
#include <Adafruit_ST7789.h>
#include <Arduino.h>
#include <Preferences.h>
#include <SPI.h>
// TCP client ile FluidNC Data port 23'e baglaniyoruz
#include <WiFi.h>
#include <driver/rtc_io.h>
#include <esp_sleep.h>


// ─── PIN TANIMLARI ────────────────────────────────────
#define ENC_CLK D2
#define ENC_DT D3
#define ENC_SW A0

#define BTN_HOME D4
#define BTN_ZERO D5
#define BTN_AXIS A6
#define BTN_SPEED A7

#define TFT_CS D10
#define TFT_DC D6
#define TFT_RST D7
#define TFT_BLK A2 // Arka ışık (Backlight) kontrolü

// ─── TFT ──────────────────────────────────────────────
Adafruit_ST7789 tft = Adafruit_ST7789(TFT_CS, TFT_DC, TFT_RST);
#define TFT_W 320
#define TFT_H 170

// ─── PİL (BATTERY) ────────────────────────────────────
#define BAT_PIN A1      // GPIO2
#define BAT_R_RATIO 2.0 // 100K + 100K voltaj bölücü oranı

// ─── RENKLER ──────────────────────────────────────────
#define C_BG 0x0000
#define C_WHITE 0xFFFF
#define C_CYAN 0x07FF
#define C_GREEN 0x07E0
#define C_RED 0xF800
#define C_YELLOW 0xFFE0
#define C_ORANGE 0xFD20
#define C_GRAY 0x4208
#define C_PANEL 0x1082
#define C_ROWHL 0x0841
#define C_DKGREEN 0x03E0

// ─── FLUIDNC UART ─────────────────────────────────────
#define FLUIDNC Serial1
#define FC_BAUD 115200

// ─── MAKİNA DURUMU ────────────────────────────────────
struct Status {
  float x, y, z;
  float wco_x, wco_y, wco_z;
  float feed;
  float spindle;
  uint8_t state;
  bool homed;
};

Status cur = {0, 0, 0, 0, 0, 0, 0, 0, 0, false};
Status prev = {0, 0, 0, 0, 0, 0, 0, 0, 0, false};

// ─── PENDANT AYARLARI ─────────────────────────────────
static const char *AXIS_STR[] = {"X", "Y", "Z"};
uint8_t selAxis = 0;

static const float STEP_VAL[] = {0.1f, 0.5f, 1.0f};
static const char *STEP_STR[] = {"0.100", "0.500", "1.000"};
static const uint8_t N_STEPS = 3;
uint8_t selStep = 0; // 0.100 mm

static const float FEED_VAL[] = {1000.0f, 2000.0f, 3000.0f};
static const char *FEED_STR[] = {"1000", "2000", "3000"};
static const uint8_t N_FEEDS = 3;
uint8_t selFeed = 1; // 2000 mm/dk

// ─── EKRAN DURUMU (MENÜ SİSTEMİ) ─────────────────────
enum ScreenState {
  SCR_MAIN,
  SCR_MENU,
  SCR_SPINDLE,
  SCR_JOG,
  SCR_STEP,
  SCR_COOLANT,
  SCR_WIFI_MENU,
  SCR_WIFI_SCAN,
  SCR_WIFI_PASS,
  SCR_WIFI_IP
};
ScreenState scrState = SCR_MAIN;
unsigned long lastActivity = 0;
#define MENU_TIMEOUT_MS 10000

bool needRedraw = true;

// Menü
#define MENU_COUNT 5
int menuIdx = 0;
static const char *MENU_LABELS[] = {
    "Spindle Kontrolu", "Jog Hizi", "Step Boyutu", "Sogutma", "WiFi Ayarlari",
};

// Spindle kontrol
int spindleTarget = 0;
#define SPINDLE_STEP 500
#define SPINDLE_MAX 20000

// Coolant
uint8_t coolantSel = 0; // 0=OFF, 1=FLOOD, 2=MIST

// ─── WIFI DEĞİŞKENLERİ ─────────────────────────────
Preferences prefs;
String wifiSSID = "";
String wifiPass = "";
uint8_t wifiIP[4] = {192, 168, 1, 1};
bool wifiConnected = false;

// ─── TCP CLIENT DEĞİŞKENLERİ ────────────────────────
WiFiClient tcpClient;
bool tcpConnected = false;
String tcpLine = ""; // TCP'den gelen veri tamponu
unsigned long lastTcpStatus = 0;
#define TCP_STATUS_INTERVAL 250 // ms -- TCP uzerinden ? sorgusu
#define FLUIDNC_TCP_PORT 23     // FluidNC Data port (Telnet)
unsigned long lastTcpReconnect = 0;
#define TCP_RECONNECT_INTERVAL 5000 // ms -- yeniden baglanti denemesi
unsigned long lastDebugLog = 0;
#define DEBUG_LOG_INTERVAL 3000 // ms -- periyodik debug log

// WiFi tarama
#define WIFI_MAX_SCAN 8
String scanSSIDs[WIFI_MAX_SCAN];
int32_t scanRSSI[WIFI_MAX_SCAN];
int scanCount = 0;
int wifiScanIdx = 0;

// WiFi alt menü
#define WIFI_MENU_COUNT 5
int wifiMenuIdx = 0;
static const char *WIFI_MENU_LABELS[] = {
    "Ag Tara", "Sifre Gir", "IP Adresi Ayarla", "Baglan / Kes", "Geri Don"};

// Karakter tekerleği (şifre girişi)
static const char CHAR_SET[] =
    "ABCDEFGHIJKLMNOPQRSTUVWXYZabcdefghijklmnopqrstuvwxyz0123456789!@#$%_-.";
#define CHAR_SET_LEN (sizeof(CHAR_SET) - 1)
int charIdx = 0;
String passBuffer = "";
#define PASS_MAX_LEN 32

// IP girişi
uint8_t ipEditIdx = 0; // hangi oktet düzenleniyor (0-3)

// ─── FLUIDNC PARSE ────────────────────────────────────
String fcLine = "";
bool fcInPkt = false;

// ─── UART AKTİFLİK TAKİBİ ────────────────────────────
unsigned long lastUartRx = 0;
#define UART_TIMEOUT_MS 500 // 500ms icerisinde UART'tan veri gelmezse pasif say
bool uartActive = false;
unsigned long lastUartStatus = 0;
#define UART_STATUS_INTERVAL 250 // ms -- UART uzerinden ? sorgusu

// ─── DEEP SLEEP ──────────────────────────────────────
#define SLEEP_TIMEOUT_MS 18000     // 2 dakika veri gelmezse uyu
#define SLEEP_WARNING_MS 13000     // 10 saniye kala uyarı göster
unsigned long lastDataReceived = 0; // UART veya TCP'den son veri zamanı
bool sleepWarningShown = false;
#define BTN_HOME_GPIO GPIO_NUM_7 // D4 = GPIO7

// Jog throttle
unsigned long lastJog = 0;
#define JOG_THROTTLE_MS 60

// ─── ENCODER ──────────────────────────────────────────
volatile int encDelta = 0;
volatile int lastClkVal = HIGH;

void IRAM_ATTR encISR() {
  int clk = digitalRead(ENC_CLK);
  int dt = digitalRead(ENC_DT);
  if (clk != lastClkVal) {
    encDelta += (dt != clk) ? 1 : -1;
    lastClkVal = clk;
  }
}

// ─── ENCODER TIKLA (Kısa + Uzun Basma) ───────────────
bool encSwPrev = HIGH;
bool encSwStable = HIGH;
bool encClicked = false;
bool encLongPress = false;
bool encLongFired = false; // uzun basma zaten tetiklendi mi
unsigned long encPressStart = 0;
unsigned long encSwChangeTime = 0;
#define ENC_SW_STABLE_MS 30
#define ENC_LONG_PRESS_MS 500 // 500ms = uzun basma

void checkEncClick() {
  bool sw = digitalRead(ENC_SW);
  // Debounce: pin değiştiyse zamanlayıcıyı sıfırla
  if (sw != encSwPrev) {
    encSwChangeTime = millis();
    encSwPrev = sw;
  }
  // Kararlı durum kontrolü (30ms boyunca aynı kaldıysa)
  if (sw != encSwStable && (millis() - encSwChangeTime > ENC_SW_STABLE_MS)) {
    bool prevStable = encSwStable;
    encSwStable = sw;
    if (sw == LOW && prevStable == HIGH) {
      // Basıldı → zamanı kaydet
      encPressStart = millis();
      encLongFired = false;
      lastActivity = millis();
    } else if (sw == HIGH && prevStable == LOW) {
      // Bırakıldı → kısa basma mı?
      if (!encLongFired) {
        encClicked = true;
        lastActivity = millis();
        Serial.println("[ENC] SHORT click");
      }
    }
  }
  // Basılı tutulurken uzun basma kontrolü
  if (encSwStable == LOW && !encLongFired &&
      (millis() - encPressStart > ENC_LONG_PRESS_MS)) {
    encLongPress = true;
    encLongFired = true; // tekrar tetikleme
    lastActivity = millis();
    Serial.println("[ENC] LONG press → BACK");
  }
}

// ─── BUTON DEBOUNCE ───────────────────────────────────
struct Btn {
  uint8_t pin;
  bool lastState;
  bool fired;
  unsigned long lastMs;
};
Btn btns[4] = {{BTN_HOME, HIGH, false, 0},
               {BTN_ZERO, HIGH, false, 0},
               {BTN_AXIS, HIGH, false, 0},
               {BTN_SPEED, HIGH, false, 0}};
#define DEBOUNCE_MS 50

// HOME tuşu uzun basma takibi
unsigned long homePressStart = 0;
bool homeLongFired = false;
#define HOME_LONG_PRESS_MS 1500 // 1.5 saniye basılı tutunca uyku

void readBtns() {
  for (int i = 0; i < 4; i++) {
    bool s = digitalRead(btns[i].pin);
    if (s != btns[i].lastState && (millis() - btns[i].lastMs > DEBOUNCE_MS)) {
      btns[i].lastMs = millis();
      btns[i].lastState = s;

      if (s == LOW) {
        if (i == 0) { // HOME butonu
          homePressStart = millis();
          homeLongFired = false;
        } else {
          btns[i].fired = true; // Diğer butonlar eskisi gibi çalışır
        }
      } else if (s == HIGH && i == 0) {
        // HOME butonu bırakıldı
        if (!homeLongFired) {
          btns[0].fired = true; // Uzun basılmadıysa kısa tık olarak kaydet
        }
      }
    }

    // HOME butonuna basılı tutuluyorsa ve 1.5 saniyeyi geçtiyse uykuya geç
    if (i == 0 && s == LOW && !homeLongFired &&
        (millis() - homePressStart > HOME_LONG_PRESS_MS)) {
      homeLongFired = true;
      Serial.println("[BTN] HOME long press -> DEEP SLEEP");
      enterDeepSleep();
    }
  }
}

// ─── FLUIDNC KOMUTLAR ─────────────────────────────────
void fcSend(const char *cmd) {
  if (uartActive) {
    FLUIDNC.println(cmd); // UART aktifse sadece UART'a gonder
  } else if (tcpConnected) {
    tcpClient.println(cmd); // UART yoksa TCP'ye gonder
  }
}

void fcJog(uint8_t axis, int8_t dir, float dist, float feed) {
  char buf[48];
  char axCh = (axis == 0) ? 'X' : (axis == 1) ? 'Y' : 'Z';
  snprintf(buf, sizeof(buf), "$J=G91 G21 %c%.4f F%.0f", axCh, dist * dir, feed);
  fcSend(buf);
}

void fcHome() { fcSend("$H"); }
void fcZero(uint8_t ax) {
  const char *cmds[] = {"G92 X0", "G92 Y0", "G92 Z0"};
  fcSend(cmds[ax]);
}

// ─── FLUIDNC PARSE ────────────────────────────────────
void parseStatus(const String &s) {
  if (s.startsWith("Idle"))
    cur.state = 0;
  else if (s.startsWith("Run"))
    cur.state = 1;
  else if (s.startsWith("Hold"))
    cur.state = 2;
  else if (s.startsWith("Alarm"))
    cur.state = 3;
  else if (s.startsWith("Home")) {
    cur.state = 4;
    cur.homed = true;
  } else if (s.startsWith("Jog"))
    cur.state = 5;
  else if (s.startsWith("Door"))
    cur.state = 6;

  int idx = s.indexOf("MPos:");
  if (idx >= 0) {
    String v = s.substring(idx + 5);
    int c1 = v.indexOf(','), c2 = v.indexOf(',', c1 + 1), e = v.indexOf('|');
    if (c1 > 0 && c2 > c1) {
      cur.x = v.substring(0, c1).toFloat();
      cur.y = v.substring(c1 + 1, c2).toFloat();
      cur.z = v.substring(c2 + 1, e > 0 ? e : (int)v.length()).toFloat();
    }
  }

  idx = s.indexOf("FS:");
  if (idx >= 0) {
    String fs = s.substring(idx + 3);
    cur.feed = fs.toFloat();
    int comma = fs.indexOf(',');
    if (comma >= 0)
      cur.spindle = fs.substring(comma + 1).toFloat();
  }

  idx = s.indexOf("WCO:");
  if (idx >= 0) {
    String w = s.substring(idx + 4);
    int c1 = w.indexOf(','), c2 = w.indexOf(',', c1 + 1), e = w.indexOf('|');
    if (c1 > 0 && c2 > c1) {
      cur.wco_x = w.substring(0, c1).toFloat();
      cur.wco_y = w.substring(c1 + 1, c2).toFloat();
      cur.wco_z = w.substring(c2 + 1, e > 0 ? e : (int)w.length()).toFloat();
    }
  }
}

void readFluidNC() {
  while (FLUIDNC.available()) {
    lastUartRx = millis(); // UART'tan veri geldi, zamani guncelle
    char c = (char)FLUIDNC.read();
    if (c == '<') {
      fcLine = "";
      fcInPkt = true;
    } else if (c == '>') {
      if (fcInPkt)
        parseStatus(fcLine);
      fcInPkt = false;
      fcLine = "";
    } else if (fcInPkt)
      fcLine += c;
  }
}

// ═══════════════════════════════════════════════════════
// ─── ÇİZİM FONKSİYONLARI ─────────────────────────────
// ═══════════════════════════════════════════════════════

static uint16_t stateColor(uint8_t s) {
  switch (s) {
  case 0:
    return C_GREEN;
  case 1:
    return C_CYAN;
  case 2:
    return C_YELLOW;
  case 3:
    return C_RED;
  case 4:
    return C_ORANGE;
  case 5:
    return C_CYAN;
  case 6:
    return C_RED;
  default:
    return C_GRAY;
  }
}

static const char *stateStr(uint8_t s) {
  switch (s) {
  case 0:
    return "IDLE ";
  case 1:
    return "RUN  ";
  case 2:
    return "HOLD ";
  case 3:
    return "ALARM";
  case 4:
    return "HOME ";
  case 5:
    return "JOG  ";
  case 6:
    return "DOOR ";
  default:
    return "?????";
  }
}

// ─── BATTERY OKUMA ────────────────────────────────────
int getBatteryPercent() {
  int raw = analogRead(BAT_PIN);
  float voltage = (raw / 4095.0) * 3.3 * BAT_R_RATIO;
  // Li-ion: 4.2V=%100, 3.0V=%0
  int pct = (int)((voltage - 3.0) / (4.2 - 3.0) * 100.0);
  if (pct > 100)
    pct = 100;
  if (pct < 0)
    pct = 0;
  return pct;
}

// ─── ANA EKRAN ────────────────────────────────────────
void drawHeader() {
  tft.fillRect(0, 0, TFT_W, 19, C_PANEL);
  tft.setTextSize(1);
  tft.setTextColor(stateColor(cur.state));
  tft.setCursor(4, 5);
  tft.print("[");
  tft.print(stateStr(cur.state));
  tft.print("]");
  tft.setTextColor(C_CYAN);
  tft.setCursor(70, 5);
  tft.print("CNC PENDANT");
  tft.setTextColor(cur.homed ? C_GREEN : C_RED);
  tft.setCursor(160, 5);
  tft.print(cur.homed ? "[HOMED]" : "[NO HOME]");

  // Pil Durumu
  int batPct = getBatteryPercent();
  tft.setCursor(227, 5);
  if (batPct > 20)
    tft.setTextColor(C_GREEN);
  else if (batPct > 5)
    tft.setTextColor(C_YELLOW);
  else
    tft.setTextColor(C_RED);
  tft.print("[");
  tft.print(batPct);
  tft.print("%]");

  // WiFi + TCP durum ikonu
  tft.setCursor(260, 5);
  if (tcpConnected) {
    tft.setTextColor(C_GREEN);
    tft.print("[TCP]");
  } else if (wifiConnected) {
    tft.setTextColor(C_YELLOW);
    tft.print("[Wifi]");
  } else {
    tft.setTextColor(C_RED);
    tft.print("[]");
  }
  tft.fillRect(296, 1, 22, 17, C_ROWHL);
  tft.setTextColor(C_YELLOW);
  tft.setCursor(301, 5);
  tft.print(AXIS_STR[selAxis]);
}
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
void loop() {
  readFluidNC();
  checkEncClick();
  readBtns();

  // UART aktiflik kontrolu (500ms icerisinde veri geldiyse aktif)
  bool prevUartActive = uartActive;
  uartActive = (millis() - lastUartRx < UART_TIMEOUT_MS);
  // Veri gelirse uyku zamanlayıcısını sıfırla
  if (uartActive)
    lastDataReceived = millis();
  if (prevUartActive && !uartActive) {
    Serial.println("[UART] UART pasif, TCP'ye geciliyor...");
    needRedraw = true;
  } else if (!prevUartActive && uartActive) {
    Serial.println("[UART] UART aktif, TCP devre disi");
    needRedraw = true;
  }

  // UART'a periyodik ? sorgusu gonder (FluidNC rapor baslatsin)
  if (millis() - lastUartStatus > UART_STATUS_INTERVAL) {
    lastUartStatus = millis();
    FLUIDNC.println("?");
  }

  // TCP loop (gelen veri oku + baglanti yonetimi)
  if (wifiConnected) {
    // TCP baglanti durumunu kontrol et
    if (tcpConnected && !tcpClient.connected()) {
      tcpConnected = false;
      Serial.println("[TCP] Connection lost!");
      needRedraw = true;
    }
    // TCP bagli degilse yeniden baglanmayi dene
    if (!tcpConnected && millis() - lastTcpReconnect > TCP_RECONNECT_INTERVAL) {
      lastTcpReconnect = millis();
      tcpStartConnection();
    }
    // TCP'den gelen veriyi her zaman oku (baglanti canli kalsin)
    if (tcpConnected) {
      tcpReadIncoming();
      // Status sorgusu sadece UART pasifse gonder
      if (!uartActive && millis() - lastTcpStatus > TCP_STATUS_INTERVAL) {
        tcpClient.println("?");
        lastTcpStatus = millis();
      }
    }
  }

  // WiFi baglanti durumunu guncelle
  if (wifiConnected && WiFi.status() != WL_CONNECTED) {
    wifiConnected = false;
    tcpConnected = false;
    Serial.println("[WIFI] Connection lost!");
    needRedraw = true;
  }

  // Periyodik debug log
  if (millis() - lastDebugLog > DEBUG_LOG_INTERVAL) {
    lastDebugLog = millis();
    unsigned long sleepRemain = 0;
    if (millis() - lastDataReceived < SLEEP_TIMEOUT_MS)
      sleepRemain = (SLEEP_TIMEOUT_MS - (millis() - lastDataReceived)) / 1000;
    Serial.printf("[DBG] UART:%s  WiFi:%s  TCP:%s  IP:%d.%d.%d.%d:%d  "
                  "Sleep:%lus  Bat:%d%%\n",
                  uartActive ? "YES" : "NO", wifiConnected ? "YES" : "NO",
                  tcpConnected ? "YES" : "NO", wifiIP[0], wifiIP[1], wifiIP[2],
                  wifiIP[3], FLUIDNC_TCP_PORT, sleepRemain,
                  getBatteryPercent());
  }

  // ── DEEP SLEEP KONTROLÜ ──────────────────────────────
  unsigned long noDataDuration = millis() - lastDataReceived;
  // 10 saniye kala uyarı göster
  if (noDataDuration > SLEEP_WARNING_MS && !sleepWarningShown &&
      scrState == SCR_MAIN) {
    sleepWarningShown = true;
    popup("UYKU: 5 SN...", C_ORANGE, 500);
  }
  // 2 dakika doldu → deep sleep
  if (noDataDuration > SLEEP_TIMEOUT_MS) {
    enterDeepSleep();
  }
  // Veri gelirse uyarı flag'ini sıfırla
  if (uartActive || tcpConnected) {
    sleepWarningShown = false;
  }

  // Her detent 2 puls üretiyor → 2'ye böl, kalanı biriktir
  static int encAccum = 0;
  noInterrupts();
  encAccum += encDelta;
  encDelta = 0;
  interrupts();
  int delta = encAccum / 2;
  encAccum %= 2; // kalan tek pulsu bir sonraki tura aktar

  if (delta != 0)
    lastActivity = millis();

  // HOME hariç, buton basıldıysa alt ekranlardan çık
  // (HOME = geri tuşu, menülerde ayrıca işleniyor)
  bool anyBtnExceptHome = btns[1].fired || btns[2].fired || btns[3].fired;
  // WiFi şifre ve IP ekranlarında AXIS butonu = confirm, çıkılmamalı
  if (anyBtnExceptHome && scrState != SCR_MAIN && scrState != SCR_WIFI_PASS &&
      scrState != SCR_WIFI_IP && scrState != SCR_WIFI_MENU &&
      scrState != SCR_WIFI_SCAN) {
    for (int i = 1; i < 4; i++)
      btns[i].fired = false;
    switchScreen(SCR_MAIN);
  }

  // 10 saniye timeout → ana ekrana dön
  if (scrState != SCR_MAIN && (millis() - lastActivity > MENU_TIMEOUT_MS)) {
    switchScreen(SCR_MAIN);
  }

  // ── EKRAN DURUMUNA GÖRE İŞLEM ──
  switch (scrState) {

  case SCR_MAIN: {
    // Uzun basma → ana ekranda işlevi yok, temizle
    if (encLongPress)
      encLongPress = false;

    // ── SPEED BUTONU: Duraklat / Devam Et ──
    if (btns[3].fired) {
      if (cur.state == 1 || cur.state == 5) {
        // RUN veya JOG → Feed Hold
        btns[3].fired = false;
        FLUIDNC.write('!');
        if (!uartActive && tcpConnected)
          tcpClient.write('!');
        popup("DURAKLANDI", C_YELLOW, 600);
        Serial.println("[PENDANT] Feed Hold sent");
        needRedraw = true;
      } else if (cur.state == 2) {
        // HOLD → Cycle Start (Devam)
        btns[3].fired = false;
        FLUIDNC.write('~');
        if (!uartActive && tcpConnected)
          tcpClient.write('~');
        popup("DEVAM EDILIYOR", C_GREEN, 600);
        Serial.println("[PENDANT] Cycle Start sent");
        needRedraw = true;
      }
      // IDLE durumunda btns[3].fired tüketilmez → aşağıda step/feed ayarı yapar
    }

    // ── ALARM DURUMU: Kurtarma ──
    if (cur.state == 3) {
      // ZERO butonu → Soft Reset (Ctrl+X)
      if (btns[1].fired) {
        btns[1].fired = false;
        FLUIDNC.write(0x18); // Ctrl+X soft reset
        if (!uartActive && tcpConnected) {
          tcpClient.write(0x18);
        }
        popup("SOFT RESET!", C_ORANGE, 1000);
        Serial.println("[PENDANT] Soft Reset sent (0x18)");
        needRedraw = true;
      }
      // HOME butonu → Alarm kilidi aç ($X)
      if (btns[0].fired) {
        btns[0].fired = false;
        fcSend("$X");
        popup("KILIT ACILDI", C_GREEN, 800);
        Serial.println("[PENDANT] Alarm unlock ($X) sent");
        needRedraw = true;
      }
      // Alarm durumunda diğer butonları yoksay
      btns[2].fired = false;
      btns[3].fired = false;
      // Alarm durumunda encoder jog engelle
      if (encClicked)
        encClicked = false;
      updateMainDisplay();
      break;
    }

    // Encoder tıkla → menüye gir
    if (encClicked) {
      encClicked = false;
      menuIdx = 0;
      switchScreen(SCR_MENU);
      break;
    }
    // Butonlar: normal çalışma
    if (btns[0].fired) {
      btns[0].fired = false;
      fcHome();
      popup("HOMING...", C_ORANGE, 300);
    }
    if (btns[1].fired) {
      btns[1].fired = false;
      fcZero(selAxis);
      char msg[10];
      snprintf(msg, sizeof(msg), "ZERO %s", AXIS_STR[selAxis]);
      popup(msg, C_GREEN, 400);
    }
    if (btns[2].fired) {
      btns[2].fired = false;
      selAxis = (selAxis + 1) % 3;
      needRedraw = true;
    }
    if (btns[3].fired) {
      btns[3].fired = false;
      selStep = (selStep + 1) % N_STEPS;
      if (selStep == 0)
        selFeed = (selFeed + 1) % N_FEEDS;
      needRedraw = true;
    }
    // Encoder → jog
    if (delta != 0) {
      uint32_t now = millis();
      if (now - lastJog >= JOG_THROTTLE_MS) {
        lastJog = now;
        int8_t dir = delta > 0 ? 1 : -1;
        float totalDist = STEP_VAL[selStep] * abs(delta);
        fcJog(selAxis, dir, totalDist, FEED_VAL[selFeed]);
      }
    }
    updateMainDisplay();
    break;
  }

  case SCR_MENU: {
    // Uzun basma veya HOME butonu → ana ekrana dön
    if (encLongPress || btns[0].fired) {
      encLongPress = false;
      btns[0].fired = false;
      switchScreen(SCR_MAIN);
      break;
    }
    if (delta != 0) {
      menuIdx += (delta > 0) ? 1 : -1;
      if (menuIdx < 0)
        menuIdx = MENU_COUNT - 1;
      if (menuIdx >= MENU_COUNT)
        menuIdx = 0;
      needRedraw = true;
    }
    if (encClicked) {
      encClicked = false;
      switch (menuIdx) {
      case 0:
        spindleTarget = (int)cur.spindle;
        switchScreen(SCR_SPINDLE);
        break;
      case 1:
        switchScreen(SCR_JOG);
        break;
      case 2:
        switchScreen(SCR_STEP);
        break;
      case 3:
        switchScreen(SCR_COOLANT);
        break;
      case 4:
        wifiMenuIdx = 0;
        switchScreen(SCR_WIFI_MENU);
        break;
      case 5:
        switchScreen(SCR_MAIN);
        break;
      }
      break;
    }
    if (needRedraw)
      drawMenuScreen();
    break;
  }
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

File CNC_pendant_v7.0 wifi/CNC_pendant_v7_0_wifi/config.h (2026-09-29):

#pragma once
/**
 * config.h — CNC Pendant v7.0 WiFi
 * Tüm sabitler, enum, struct ve extern tanımları
 */

#include <Arduino.h>
#include <Adafruit_GFX.h>
#include <Adafruit_ST7789.h>
#include <SPI.h>
#include <Preferences.h>
#include <WiFi.h>
#include <ESPmDNS.h>
#include <esp_sleep.h>
#include <driver/rtc_io.h>

// ─── PIN TANIMLARI ────────────────────────────────────
#define ENC_CLK D2
#define ENC_DT  D3
#define ENC_SW  A0

#define BTN_HOME  D4
#define BTN_ZERO  D5
#define BTN_AXIS  A6
#define BTN_SPEED A7

#define TFT_CS  D10
#define TFT_DC  D6
#define TFT_RST D7
#define TFT_BLK A2  // Arka ışık (Backlight) kontrolü — PWM

// ─── TFT ──────────────────────────────────────────────
#define TFT_W 320
#define TFT_H 170

// ─── PİL (BATTERY) ────────────────────────────────────
#define BAT_PIN       A1      // GPIO2
#define BAT_R_RATIO   2.0f    // 100K + 100K voltaj bölücü oranı
#define BAT_READ_INTERVAL 10000  // 10 saniyede bir oku (#9)
#define BAT_SAMPLES   8          // Gürültü filtresi (#9)

// ─── RENKLER ──────────────────────────────────────────
#define C_BG      0x0000
#define C_WHITE   0xFFFF
#define C_CYAN    0x07FF
#define C_GREEN   0x07E0
#define C_RED     0xF800
#define C_YELLOW  0xFFE0
#define C_ORANGE  0xFD20
#define C_GRAY    0x4208
#define C_PANEL   0x1082
#define C_ROWHL   0x0841
#define C_DKGREEN 0x03E0

// ─── FLUIDNC UART ─────────────────────────────────────
#define FLUIDNC Serial1
#define FC_BAUD 115200

// ─── MAKİNA DURUMU ENUM (#13) ─────────────────────────
enum MachineState : uint8_t {
  ST_IDLE  = 0,
  ST_RUN   = 1,
  ST_HOLD  = 2,
  ST_ALARM = 3,
  ST_HOME  = 4,
  ST_JOG   = 5,
  ST_DOOR  = 6
};

// ─── STATUS STRUCT ────────────────────────────────────
struct Status {
  float x, y, z;
  float wco_x, wco_y, wco_z;
  float feed;
  float spindle;
  uint8_t state;
  bool homed;
  uint8_t feedOv;    // Feed override %
  uint8_t rapidOv;   // Rapid override %
  uint8_t spindleOv; // Spindle override %
  uint8_t alarmCode;  // Alarm kodu (1-10)
  float sdPercent;    // SD kart ilerleme yuzdesi (0.0 - 100.0)
  uint32_t sdLine;    // G-code satir no
};

// ─── BUTON STRUCT ─────────────────────────────────────
struct Btn {
  uint8_t pin;
  bool lastState;
  bool fired;
  unsigned long lastMs;
};

// ─── EKRAN DURUMU (MENÜ SİSTEMİ) ─────────────────────
enum ScreenState {
  SCR_MAIN,
  SCR_MENU,
  SCR_SPINDLE,
  SCR_JOG,
  SCR_STEP,
  SCR_COOLANT,
  SCR_WIFI_MENU,
  SCR_WIFI_SCAN,
  SCR_WIFI_PASS,
  SCR_WIFI_IP,
  SCR_FEED_OV,
  SCR_SPINDLE_OV,
  SCR_OVERRIDE_SEL,
  SCR_PROBE,         // #18 Z Probe
  SCR_SD_LIST,        // #21 SD Kart dosya listesi
  SCR_SD_PREVIEW,     // SD Kart dosya onizleme & baslatma onayi
  SCR_JOB_PROGRESS,   // Canli is takibi ve ilerleme ekrani
};

// ─── POPUP STRUCT (#4 non-blocking) ──────────────────
struct PopupState {
  bool active;
  unsigned long startMs;
  unsigned long durMs;
};

// POPUP SURE SABITLERI
#define POPUP_DUR_FAST    600
#define POPUP_DUR_NORMAL  800
#define POPUP_DUR_LONG    1000

// ─── WiFi BAĞLANTI STATE MACHINE (#5) ────────────────
enum WifiConnState { WCS_IDLE, WCS_CONNECTING, WCS_CONNECTED, WCS_FAILED };

// ─── ZAMANLAMA SABİTLERİ ──────────────────────────────
#define DEBOUNCE_MS        50
#define ENC_SW_STABLE_MS   30
#define ENC_LONG_PRESS_MS  500
#define HOME_LONG_PRESS_MS 1500  // 1.5 saniye basılı tutunca uyku

#define MENU_TIMEOUT_MS    10000
#define JOG_THROTTLE_MS    60

#define SPINDLE_STEP  500
#define SPINDLE_MAX   20000

#define UART_TIMEOUT_MS       500
#define UART_STATUS_INTERVAL  250

#define TCP_STATUS_INTERVAL    250
#define FLUIDNC_TCP_PORT       23
#define TCP_RECONNECT_INTERVAL 5000
#define DEBUG_LOG_INTERVAL     3000

#define SLEEP_TIMEOUT_MS  120000   // 2 dakika veri gelmezse uyu
#define SLEEP_WARNING_MS  110000   // 10 saniye kala uyarı göster
#define BTN_HOME_GPIO     GPIO_NUM_7  // D4 = GPIO7

#define WIFI_MAX_SCAN     8
#define PASS_MAX_LEN      32

// ─── FLOAT KARŞILAŞTIRMA EPSİLON (#8) ────────────────
#define POS_EPSILON 0.0005f

// ─── PARLAKLIK (#19) ──────────────────────────────────
#define BRIGHTNESS_LEVELS 4
static const uint8_t BRIGHTNESS_VAL[] = {64, 128, 192, 255};

// ─── Z PROBE SABİTLERİ (#18) ─────────────────────────
#define PROBE_DEPTH_DEFAULT -30
#define PROBE_FEED_DEFAULT  100
#define PROBE_DEPTH_MIN    -100
#define PROBE_DEPTH_MAX     -5
#define PROBE_FEED_MIN      10
#define PROBE_FEED_MAX      500
#define PROBE_RETRACT_DEFAULT 5
#define PROBE_RETRACT_MIN     1
#define PROBE_RETRACT_MAX     50
#define PROBE_PLATE_DEFAULT   2    // Plaka kalinligi (mm)
#define PROBE_PLATE_MIN       0
#define PROBE_PLATE_MAX       20

// PARCA SIFIRINA GIT (GO TO ZERO)
#define GOTO_ZERO_Z_CLEARANCE 10
#define GOTO_ZERO_FEED        3000

// SD KART
#define SD_MAX_FILES 8
#define SD_PREVIEW_MAX_LINES 200
#define SD_PREVIEW_LINE_LEN  36
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

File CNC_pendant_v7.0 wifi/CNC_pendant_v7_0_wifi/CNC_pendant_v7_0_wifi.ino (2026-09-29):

/**
 * =====================================================
 *  CNC Pendant — Arduino Nano ESP32
 *  v7.0 wifi — Modüler yapı, non-blocking, iyileştirmeler
 * =====================================================
 *
 * DEĞIŞIKLIKLER (v6.0 → v7.0):
 *   #1  RUN durumunda jog engelleme (güvenlik)
 *   #4  Non-blocking popup (delay kaldırıldı)
 *   #5  Non-blocking WiFi connect (state machine)
 *   #6  Async WiFi scan (donma yok)
 *   #7  Char buffer ile heap fragmentation düzeltme
 *   #8  Float epsilon karşılaştırma
 *   #9  Pil okuması önbellekleme (10sn, 8x ortalama)
 *   #10 Flicker azaltma (partial update)
 *   #12 Modüler dosya yapısı
 *   #13 MachineState enum
 *   #14 fcSendRealtime merkezi kullanım
 *   #15 Override gauge birleştirme
 *   #17 Jog Cancel (0x85) — step motor güvenliği
 *   #18 Z Probe ekranı
 *   #19 PWM parlaklık kontrolü
 *   #20 Ayar kalıcılığı (Preferences)
 *
 * FluidNC config.yaml:
 *   uart1:
 *     txd_pin: gpio.38
 *     rxd_pin: gpio.39
 *     baud: 115200
 *     mode: 8N1
 *   uart_channel1:
 *     uart_num: 1
 *     report_interval_ms: 75
 *     message_level: Error
 *
 * BAĞLANTI: (aynı v2.8)
 *   Encoder CLK→D2, DT→D3, SW→A0
 *   Butonlar HOME→D4, ZERO→D5, AXIS→A6, SPEED→A7
 *   TFT CS→D10, DC→D6, RST→D7, BLK→A2
 *   UART RX1→D9, TX1→D8
 *
 * KÜTÜPHANEler: Adafruit ST7789, Adafruit GFX Library
 * =====================================================
 */

#include "config.h"
#include "input.h"
#include "fluidnc.h"
#include "wifi_mgr.h"
#include "display.h"

// ═══════════════════════════════════════════════════════
// ─── GLOBAL DEĞİŞKEN TANIMLARI ───────────────────────
// (Extern bildirimleri config.h'de)
// ═══════════════════════════════════════════════════════

Adafruit_ST7789 tft = Adafruit_ST7789(TFT_CS, TFT_DC, TFT_RST);

Status cur  = {0, 0, 0, 0, 0, 0, 0, 0, ST_IDLE, false, 100, 100, 100};
Status prev = {0, 0, 0, 0, 0, 0, 0, 0, ST_IDLE, false, 100, 100, 100};

ScreenState scrState = SCR_MAIN;
bool needRedraw = true;
unsigned long lastActivity = 0;

uint8_t selAxis = 0;
uint8_t selStep = 0;     // 0.100 mm
uint8_t selFeed = 1;     // 2000 mm/dk

int menuIdx = 0;
uint8_t ovSelIdx = 0;    // Override seçim (0=Feed, 1=Spindle)
int spindleTarget = 0;
uint8_t coolantSel = 0;  // 0=OFF, 1=FLOOD, 2=MIST

unsigned long lastDataReceived = 0;
bool sleepWarningShown = false;
unsigned long lastJog = 0;

// #19 Parlaklık
uint8_t brightnessIdx = BRIGHTNESS_LEVELS - 1;  // Varsayılan tam parlaklık

// #18 Z Probe
int probeDepth = PROBE_DEPTH_DEFAULT;
int probeFeed = PROBE_FEED_DEFAULT;
int probeRetract = PROBE_RETRACT_DEFAULT;
uint8_t probeParamIdx = 0;  // 0=derinlik, 1=hız, 2=geri çekilme
int probePlate = PROBE_PLATE_DEFAULT;


// ═══════════════════════════════════════════════════════
// ─── EKRAN GEÇİŞ ─────────────────────────────────────
// ═══════════════════════════════════════════════════════

void switchScreen(ScreenState s) {
  scrState = s;
  needRedraw = true;
  lastActivity = millis();
}

// ═══════════════════════════════════════════════════════
// ─── DEEP SLEEP ──────────────────────────────────────
// ═══════════════════════════════════════════════════════

void enterDeepSleep() {
  Serial.println("[SLEEP] Entering deep sleep...");
  // #20 Uykuya geçmeden önce ayarları kaydet
  saveUserPrefs();

  // Ekranda uyku mesajı göster
  tft.fillScreen(C_BG);
  tft.setTextSize(2);
  tft.setTextColor(C_YELLOW);
  tft.setCursor(100, 40);
  tft.print("UYKU MODU");
  tft.setTextSize(1);
  tft.setTextColor(C_GRAY);
  tft.setCursor(50, 80);
  tft.print("FluidNC veri yok - enerji tasarrufu");
  tft.setTextColor(C_GREEN);
  tft.setCursor(60, 110);
  tft.print("Uyandirmak icin HOME tusuna basin");
  delay(2000);

  // #19 Ekran arka ışığını PWM ile kapat
  analogWrite(TFT_BLK, 0);
  pinMode(TFT_CS, OUTPUT);
  digitalWrite(TFT_CS, HIGH);
  tft.enableDisplay(false);  // ST7789 uyku komutu

  // WiFi kapat
  if (wifiConnected) {
    tcpClient.stop();
    if (mdnsStarted) {
      MDNS.end();
      mdnsStarted = false;
    }
    WiFi.disconnect();
  }
  WiFi.mode(WIFI_OFF);

  // ÖNEMLİ: HOME butonunun bırakılmasını bekle
  while (digitalRead(BTN_HOME) == LOW) {
    delay(10);
  }
  delay(50);  // debounce

  // Uyku sırasında pull-up aktif tut
  rtc_gpio_pullup_en(BTN_HOME_GPIO);
  rtc_gpio_pulldown_dis(BTN_HOME_GPIO);

  // HOME butonu (GPIO7) ile uyanma ayarla (LOW = basılı)
  esp_sleep_enable_ext0_wakeup(BTN_HOME_GPIO, LOW);
  esp_deep_sleep_start();
}

// ═══════════════════════════════════════════════════════
// ─── SETUP ────────────────────────────────────────────
// ═══════════════════════════════════════════════════════
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

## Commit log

2026-02-22 CNC MAKİNASI EL ÇARKI
    [KNOB PARÇASI SABİTLEME.stl, KNOOB PARÇASI.stl, TUŞ.stl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]
2026-09-07 ip ve donma sorunu çözüldü
    [kumanda.stl]
2026-09-22 7.0
    Yeni özellik ve iyileştirme
    [KNOB PARÇASI SABİTLEME.stl, KNOOB PARÇASI.stl, TUŞ.stl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]
